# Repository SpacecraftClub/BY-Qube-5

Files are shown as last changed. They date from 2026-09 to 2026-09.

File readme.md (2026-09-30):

# BY-QUBE-5
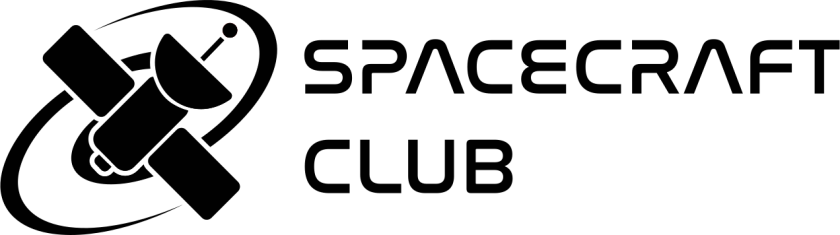
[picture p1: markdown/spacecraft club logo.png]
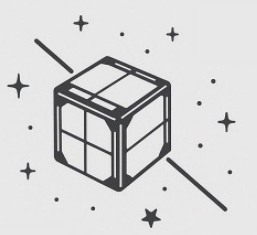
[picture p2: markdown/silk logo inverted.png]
<br>
The fith itteration of BYU Spacecraft's PocketQube project. Based on the success of BY-QUBE-4 we aim to itterate and improve on our previous designs.
## Preamble
For the last 4 years, undergraduate students have participated in the BY-QUBE 1p pocketqube program. 
### BY-QUBE-4
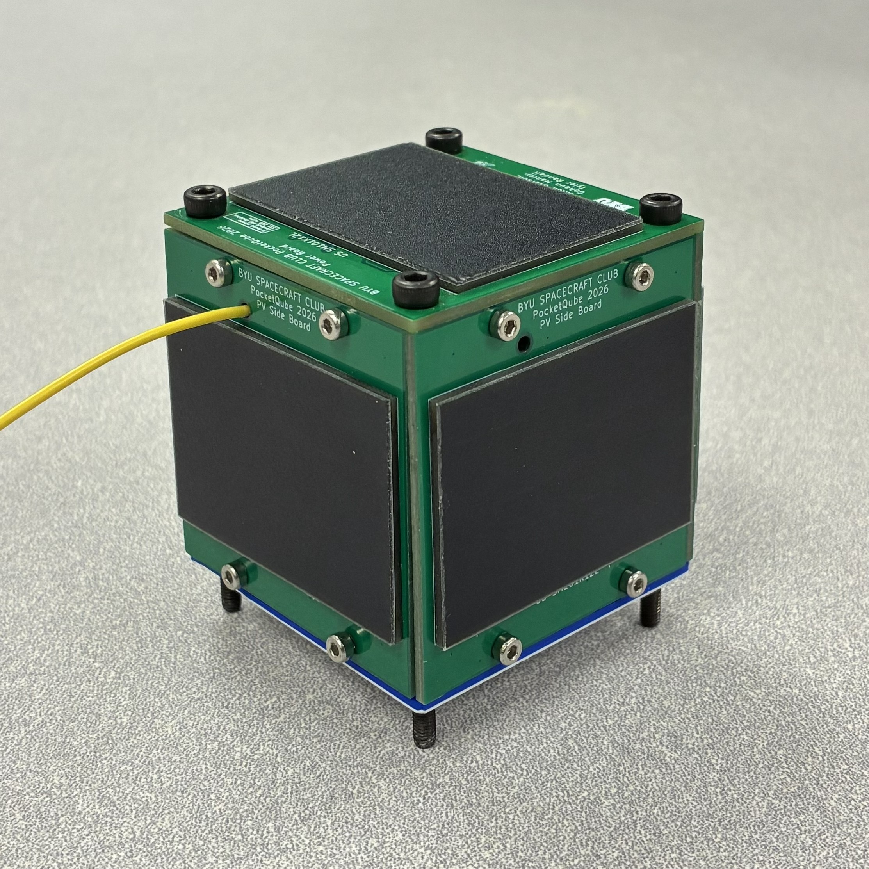
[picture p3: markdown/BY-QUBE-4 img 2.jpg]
BY-QUBE-4 1
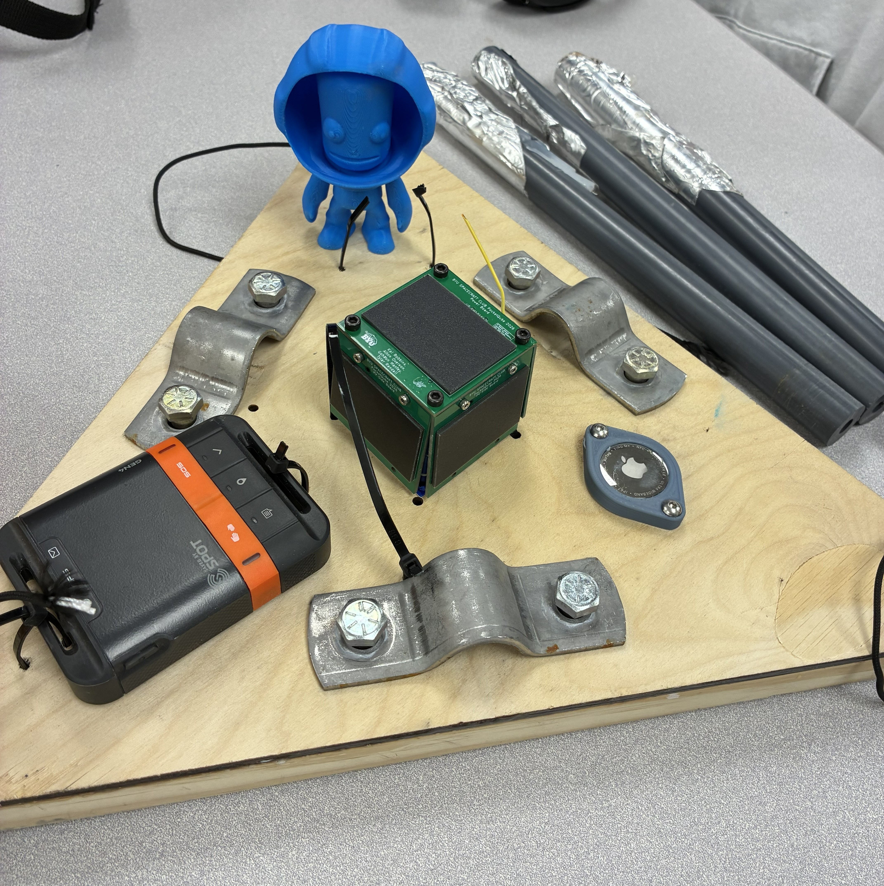
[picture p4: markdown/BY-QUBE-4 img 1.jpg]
BY-QUBE-4 1

## Improvements for this year
### Improved board stackup design
Using a blade design for interfacing the boards into eachother rather than crimped wire interfaces. This will increase durability, simplify the assembly process, and allow for easy swapping of subsystems as needed.

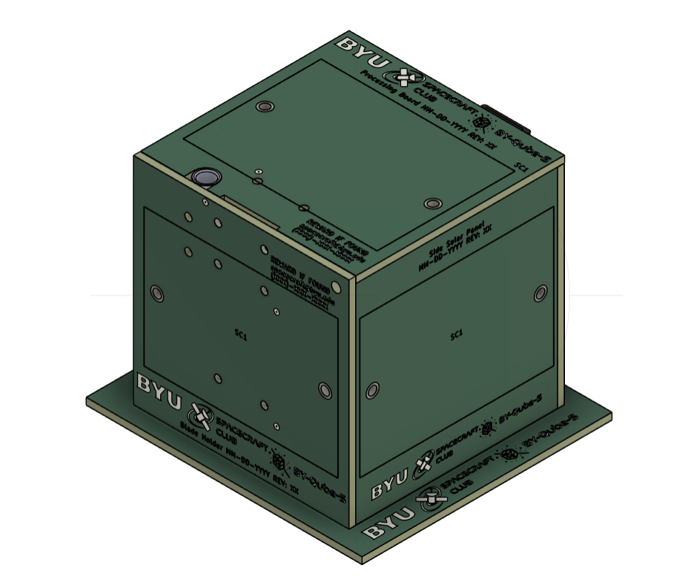
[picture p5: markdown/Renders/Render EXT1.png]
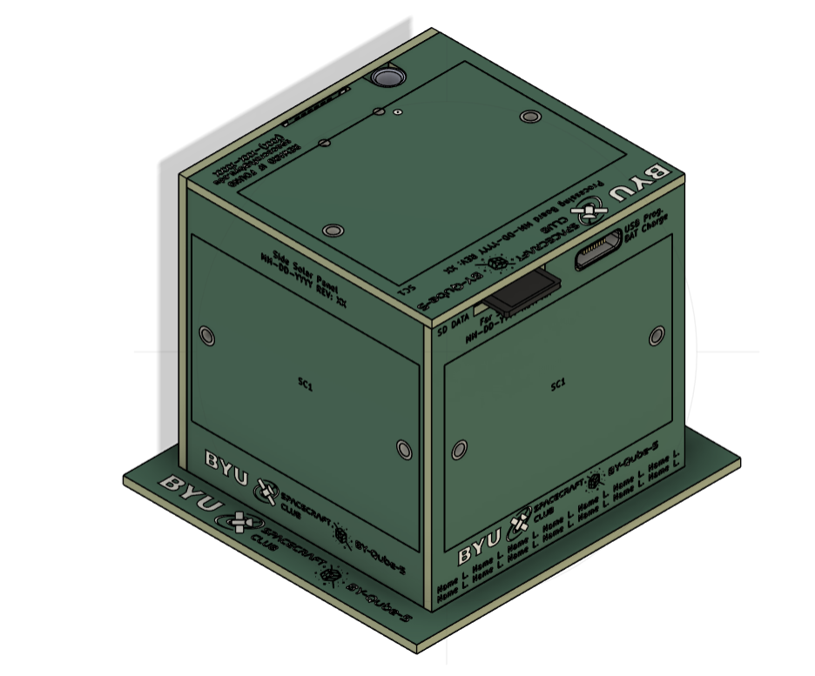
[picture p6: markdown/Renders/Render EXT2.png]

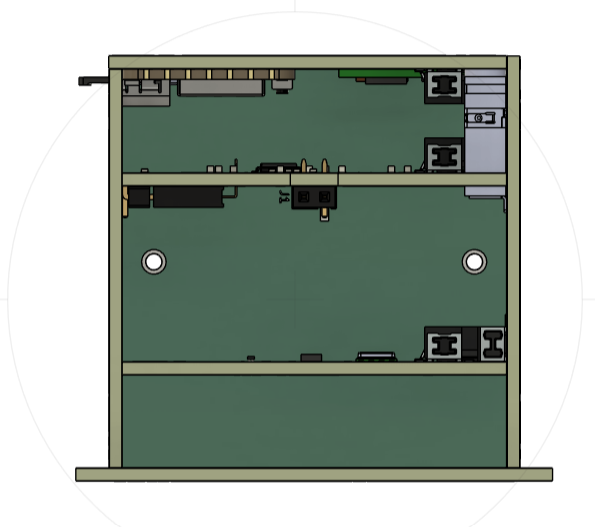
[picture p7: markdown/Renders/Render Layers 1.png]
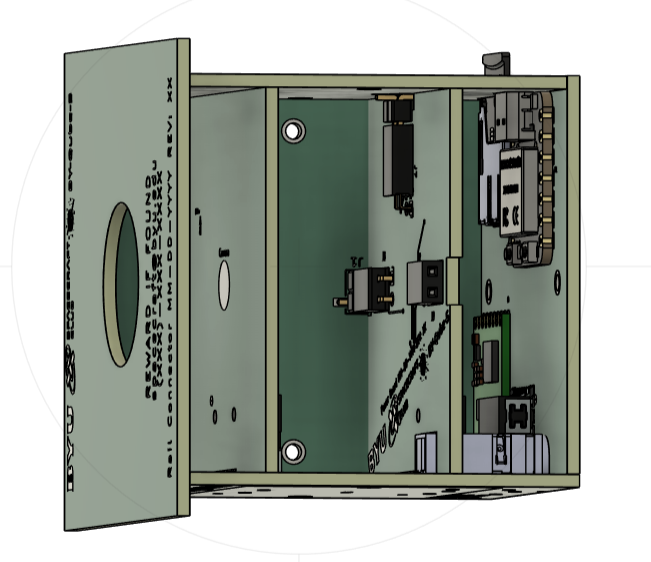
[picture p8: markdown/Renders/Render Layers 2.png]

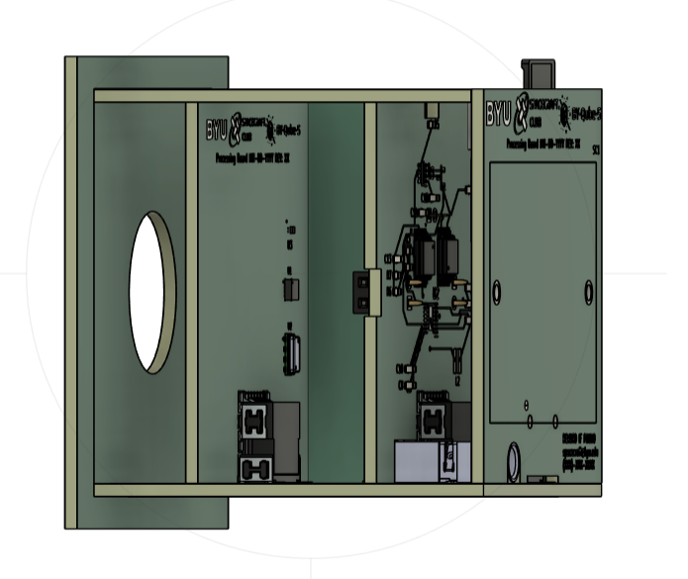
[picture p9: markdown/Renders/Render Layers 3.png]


##

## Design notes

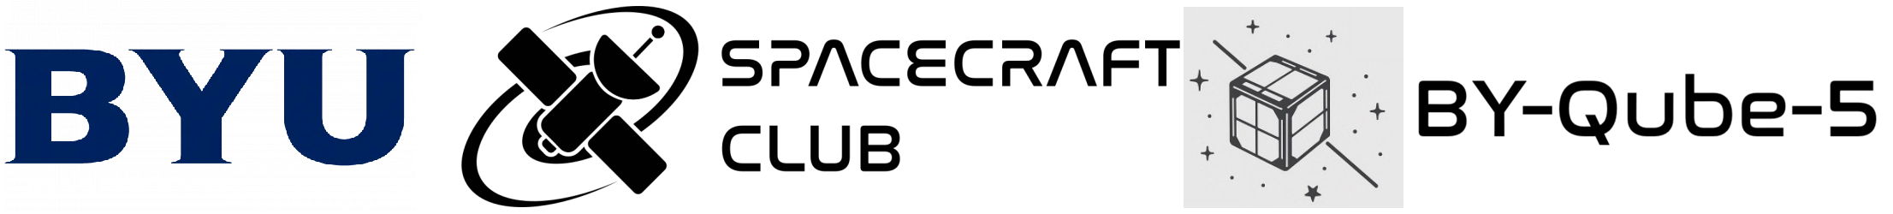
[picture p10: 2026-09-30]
Processing Board/Image Assets/Full Silk BY-Qube5.png

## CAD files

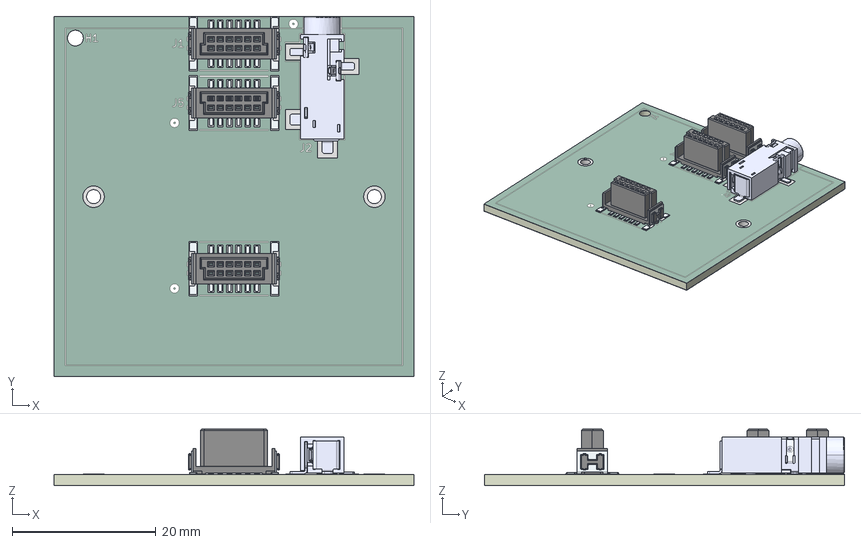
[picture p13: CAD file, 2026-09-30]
Blade Holder/Blade Holder Mockup.step
50.0 x 50.0 x 7.87 mm
Same_Sky_SJ-3524-SMT-TR
Blade Holder_pad
Blade Holder_silkscreen x 2
Blade Holder_soldermask x 2
Blade Holder_PCB

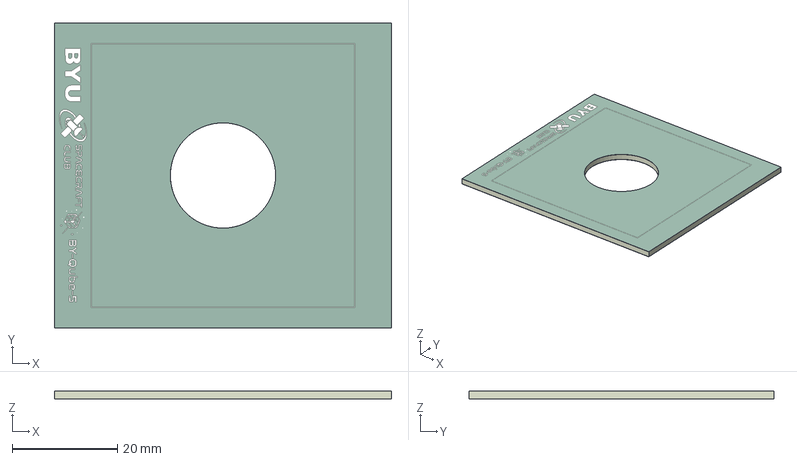
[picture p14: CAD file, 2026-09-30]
Bottom Rail Plate/Bottom Rail Mockup.step
64.0 x 58.0 x 1.66 mm
Bottom Rail Plate_silkscreen x 2
Bottom Rail Plate_soldermask x 2
Bottom Rail Plate_PCB

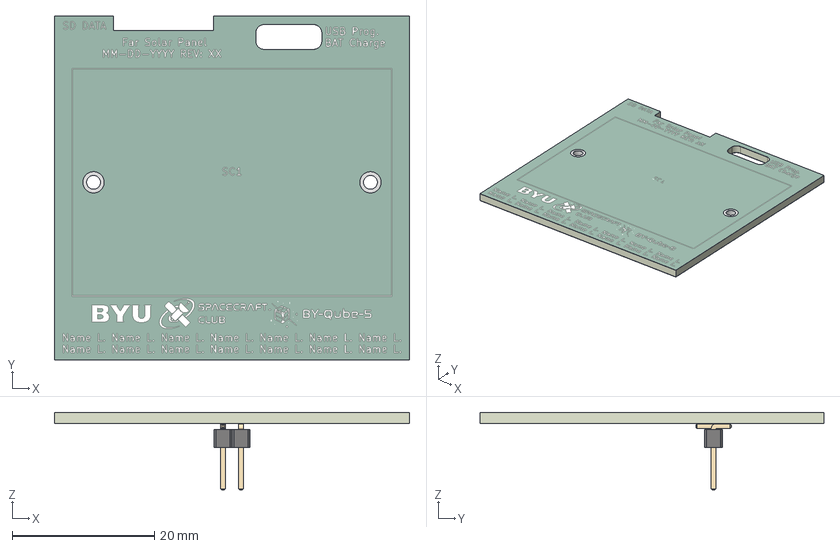
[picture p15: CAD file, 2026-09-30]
Far Solar Panel Board/Far Solar Mockup.step
50.0 x 48.4 x 11.0 mm
PinHeader_1x02_P2.54mm_Vertical_SMD_Pin1Right
Far Solar Panel Board_pad
Far Solar Panel Board_silkscreen x 2
Far Solar Panel Board_soldermask x 2
Far Solar Panel Board_PCB

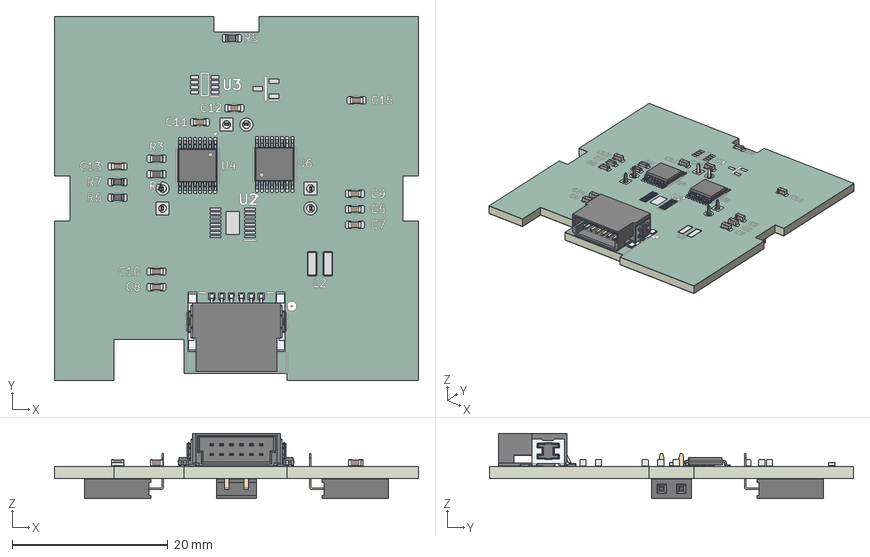
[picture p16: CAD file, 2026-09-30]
Power Board/Power Board Mockup.step
46.8 x 46.8 x 8.42 mm
C_0603_1608Metric x 9
R_0603_1608Metric x 5
TSSOP-16_4.4x5mm_P0.65mm x 2
PinSocket_1x02_P2.54mm_Horizontal x 3
Power Board_copper
Power Board_pad
Power Board_via
Power Board_silkscreen x 2
Power Board_soldermask x 2
Power Board_PCB

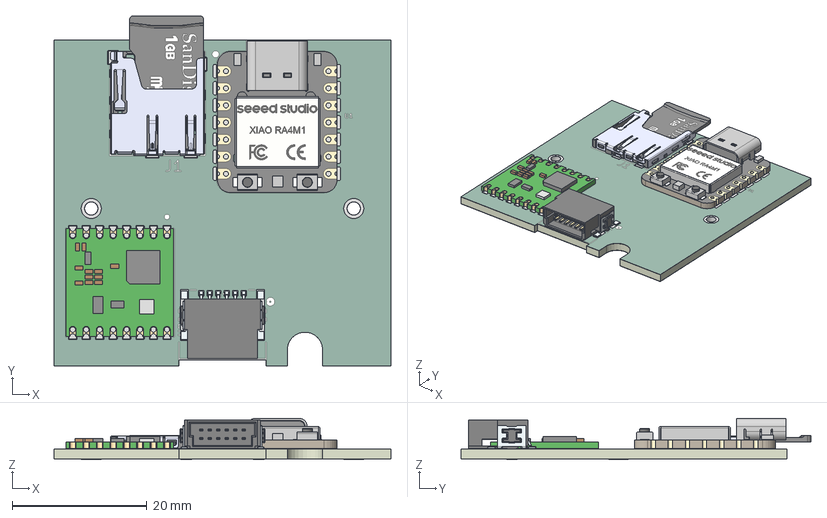
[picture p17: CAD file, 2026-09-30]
Processing Board/Processing Board Mockup.step
50.0 x 52.0 x 6.16 mm
BOSS-EXTRUDE14_8_
BOSS-EXTRUDE7_4_
BOSS-EXTRUDE7_3_
BOSS-EXTRUDE14_4_
BOSS-EXTRUDE14_2_
BOSS-EXTRUDE14_11_
BOSS-EXTRUDE7_7_
BOSS-EXTRUDE14_9_
BOSS-EXTRUDE14_3_
BOSS-EXTRUDE14_7_
MIRROR2
BOSS-EXTRUDE14_5_
BOSS-EXTRUDE14_12_
BOSS-EXTRUDE7_8_
BOSS-EXTRUDE7_1_
BOSS-EXTRUDE14_10_
BOSS-EXTRUDE7_9_
BOSS-EXTRUDE14_6_
BOSS-EXTRUDE14_1_
BOSS-EXTRUDE7_6_
BOSS-EXTRUDE7_2_
CUT-EXTRUDE5
BOSS-EXTRUDE7_5_
Button (1) x 2
Shield (1)
MEM2061-01-188-00-A_REVA
Micro_SD
RFM95W-868S2
Processing Board_pad
Processing Board_silkscreen x 2
Processing Board_soldermask x 2
Processing Board_PCB

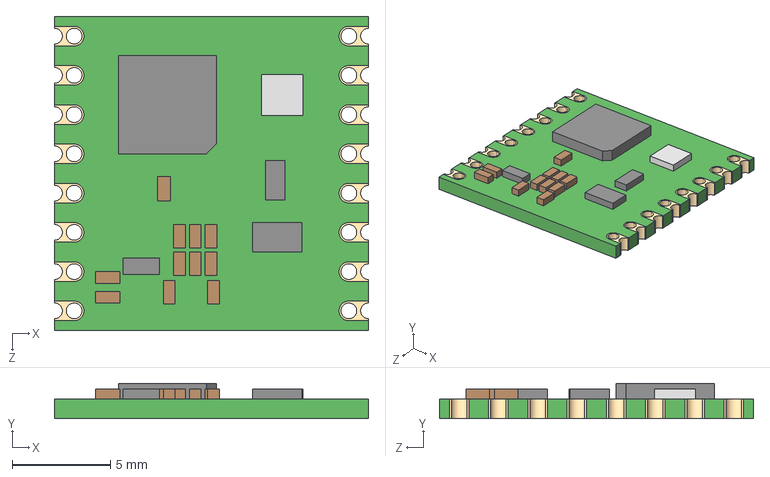
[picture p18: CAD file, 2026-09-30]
Processing Board/RFM95W-868S2/RFM95W-868S2.step
16.0 x 1.80 x 16.0 mm

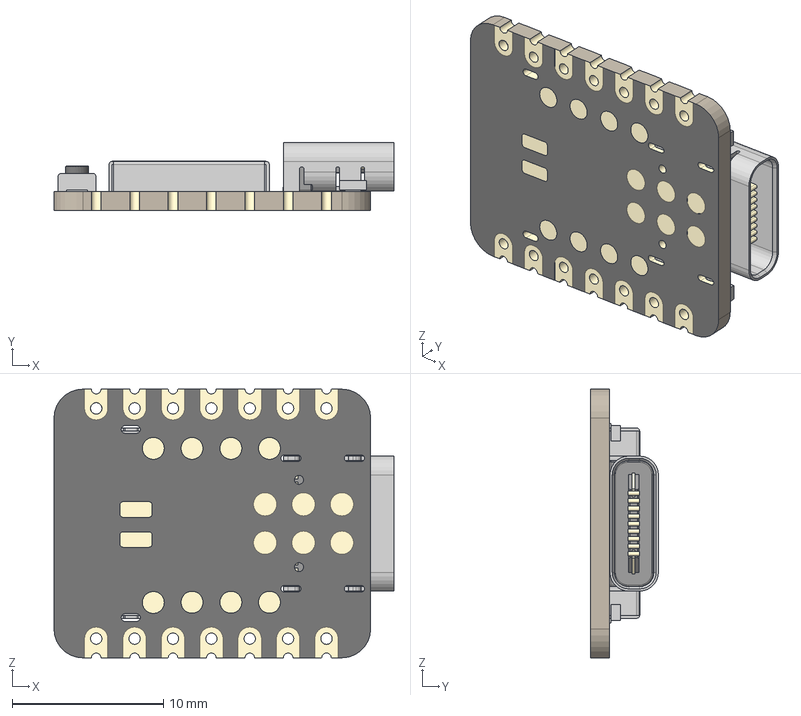
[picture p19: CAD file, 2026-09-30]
Processing Board/Seeed Studio XIAO Series Library/seeed-studio-xiao-ra4m1-v3.step
22.5 x 4.49 x 17.8 mm
BOSS-EXTRUDE14_8_
BOSS-EXTRUDE7_4_
BOSS-EXTRUDE7_3_
BOSS-EXTRUDE14_4_
BOSS-EXTRUDE14_2_
BOSS-EXTRUDE14_11_
BOSS-EXTRUDE7_7_
BOSS-EXTRUDE14_9_
BOSS-EXTRUDE14_3_
BOSS-EXTRUDE14_7_
MIRROR2
BOSS-EXTRUDE14_5_
BOSS-EXTRUDE14_12_
BOSS-EXTRUDE7_8_
BOSS-EXTRUDE7_1_
BOSS-EXTRUDE14_10_
BOSS-EXTRUDE7_9_
BOSS-EXTRUDE14_6_
BOSS-EXTRUDE14_1_
BOSS-EXTRUDE7_6_
BOSS-EXTRUDE7_2_
CUT-EXTRUDE5
BOSS-EXTRUDE7_5_
Button (1) x 2
Shield

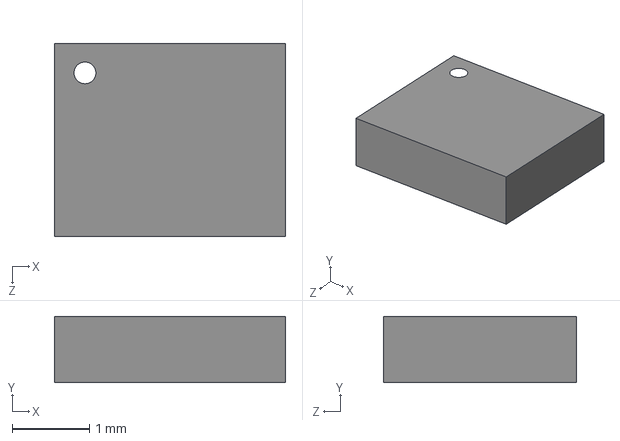
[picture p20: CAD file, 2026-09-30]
Sensor Board/LSMDSOXTR/LSM6DSOXTR.step
3.00 x 0.86 x 2.50 mm

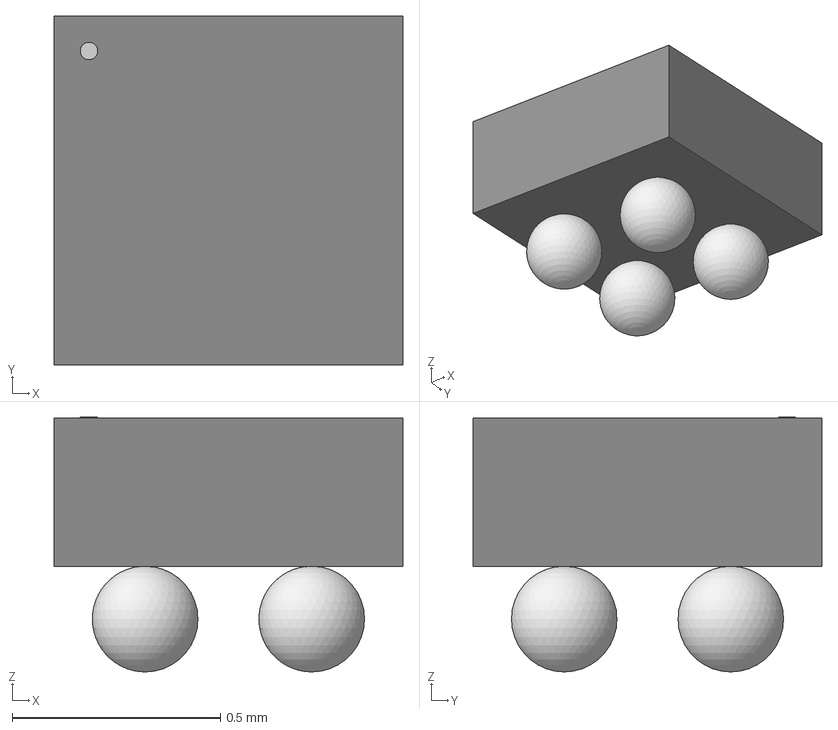
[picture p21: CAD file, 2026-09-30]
Sensor Board/MMC5603NJ/WLP4_0P82X0P82_MEM.step
0.838 x 0.838 x 0.612 mm

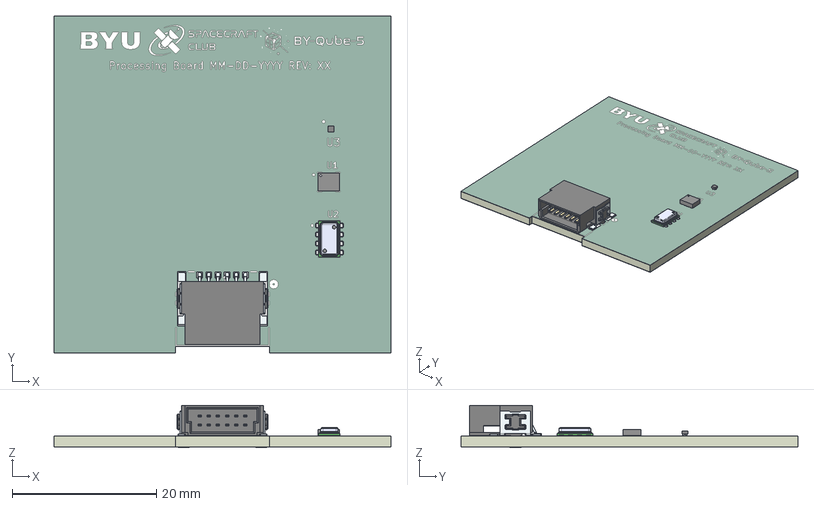
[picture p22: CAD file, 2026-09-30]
Sensor Board/Sensor Mockup.step
46.8 x 46.8 x 5.87 mm
MS5611-01BA03
WLP4_0P82X0P82_MEM
LSM6DSOXTR
Sensor Board_pad
Sensor Board_silkscreen x 2
Sensor Board_soldermask x 2
Sensor Board_PCB

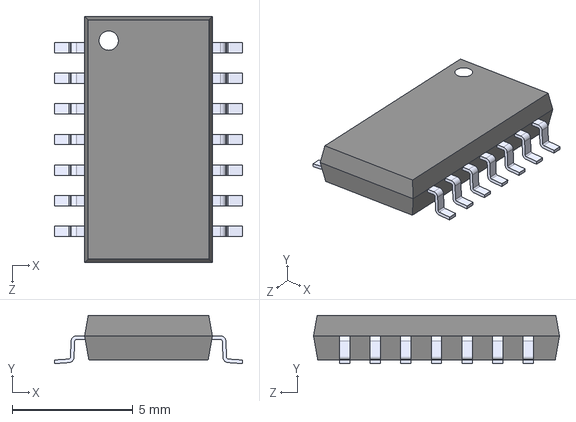
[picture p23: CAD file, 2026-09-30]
Sensor Board/SN74LVC125ANSR/SN74LVC125ANSR.step
7.80 x 2.00 x 10.2 mm

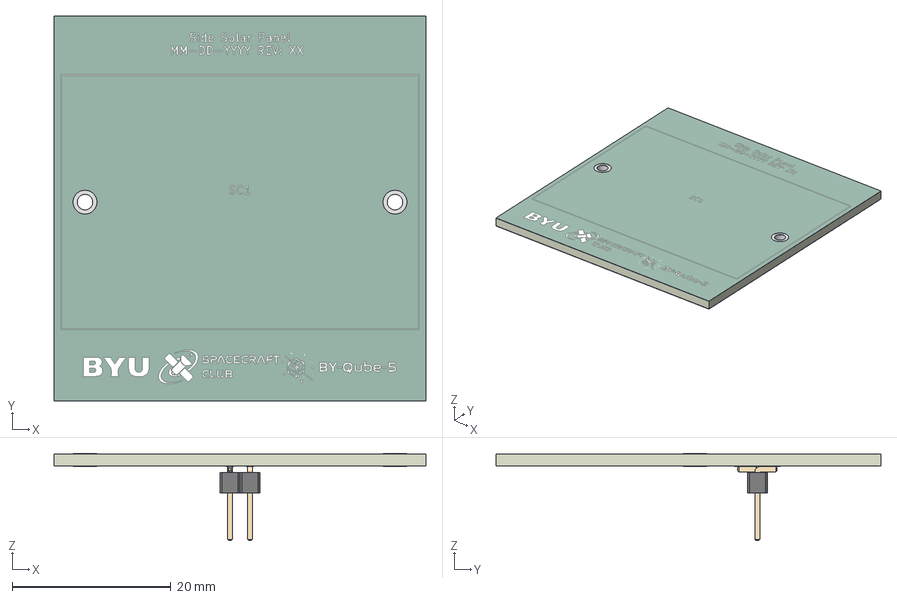
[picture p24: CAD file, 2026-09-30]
Side Solar Panel Board/Side Solar Mockup.step
46.8 x 48.4 x 11.0 mm
PinHeader_1x02_P2.54mm_Vertical_SMD_Pin1Right
Side Solar Panel Board_pad
Side Solar Panel Board_silkscreen x 2
Side Solar Panel Board_soldermask x 2
Side Solar Panel Board_PCB

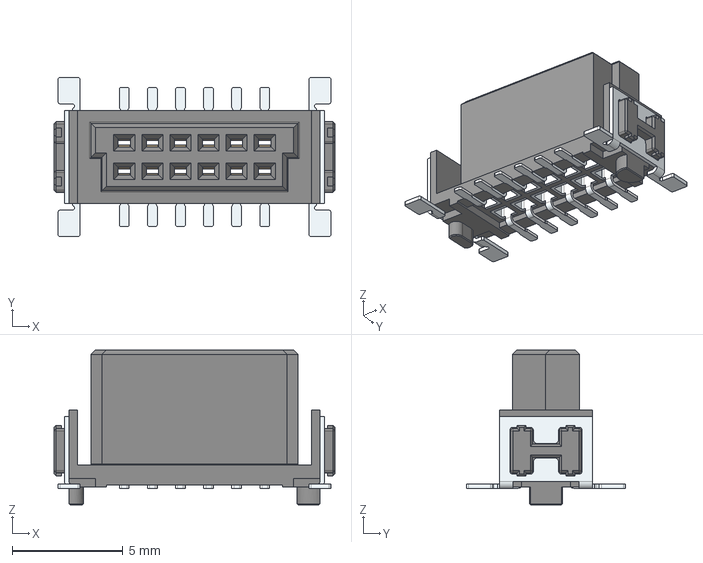
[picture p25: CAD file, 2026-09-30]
Blade Holder/M55-6001242R/m55-6001242r.stp
12.7 x 7.20 x 7.00 mm

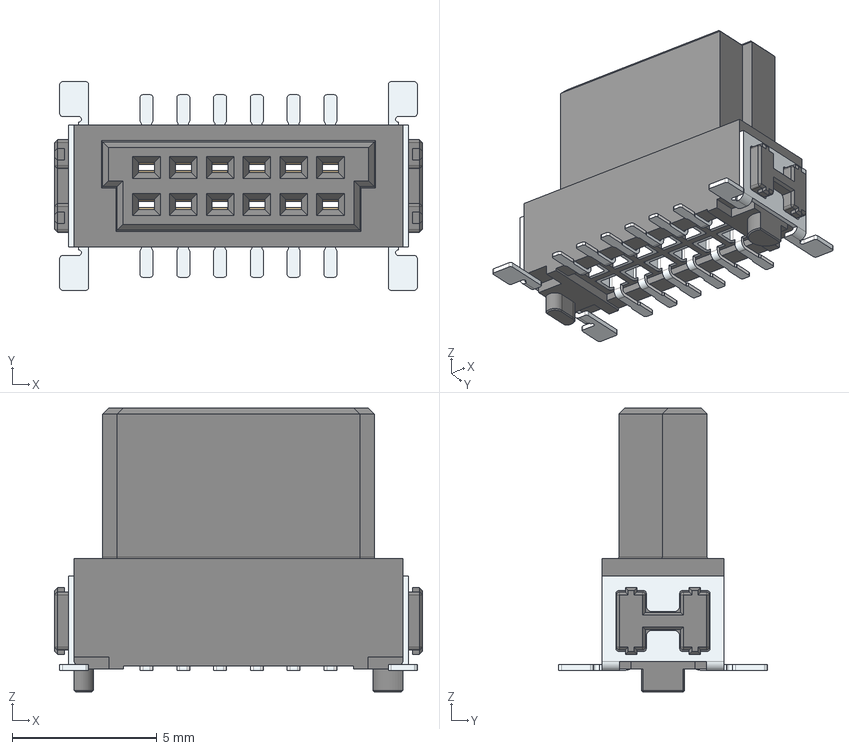
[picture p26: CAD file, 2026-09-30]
Processing Board/M55-6011242R/M55-6011242R.stp
12.7 x 7.20 x 9.80 mm
M55-60112_MOULD
M55-601_CONTACT x 12
M55-700_STRAP x 2

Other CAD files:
Processing Board/M55_7101242R/m55-7101242r.stp
Sensor Board/M55_7101242R/m55-7101242r.stp

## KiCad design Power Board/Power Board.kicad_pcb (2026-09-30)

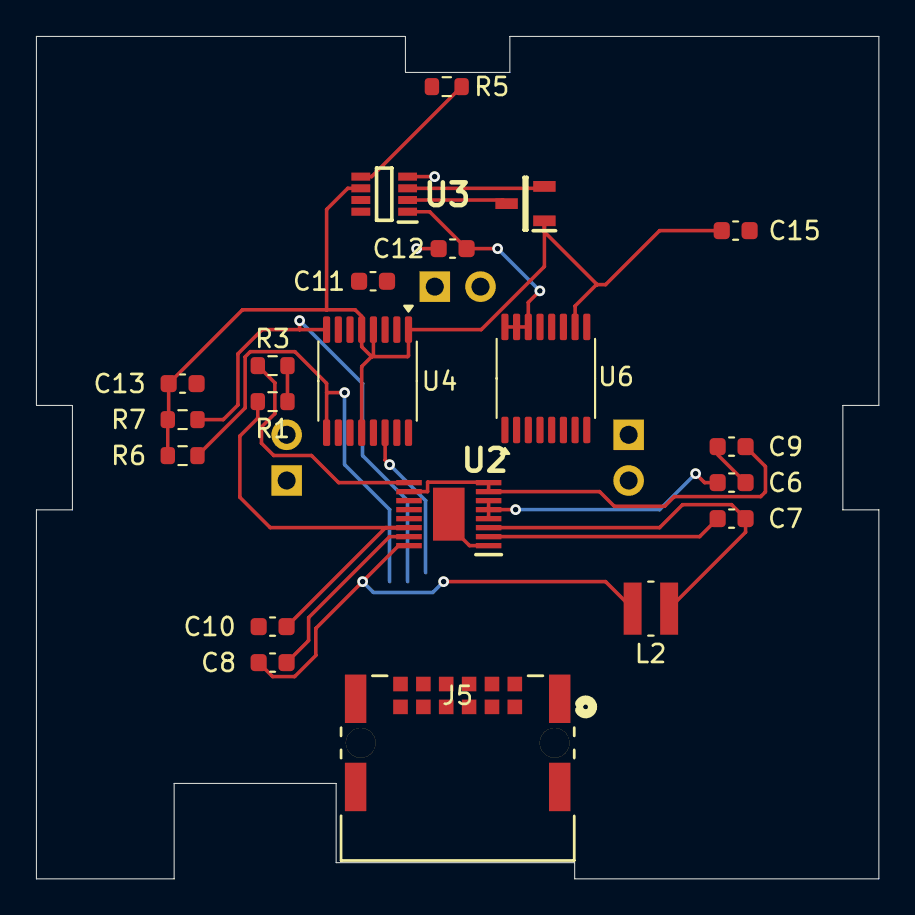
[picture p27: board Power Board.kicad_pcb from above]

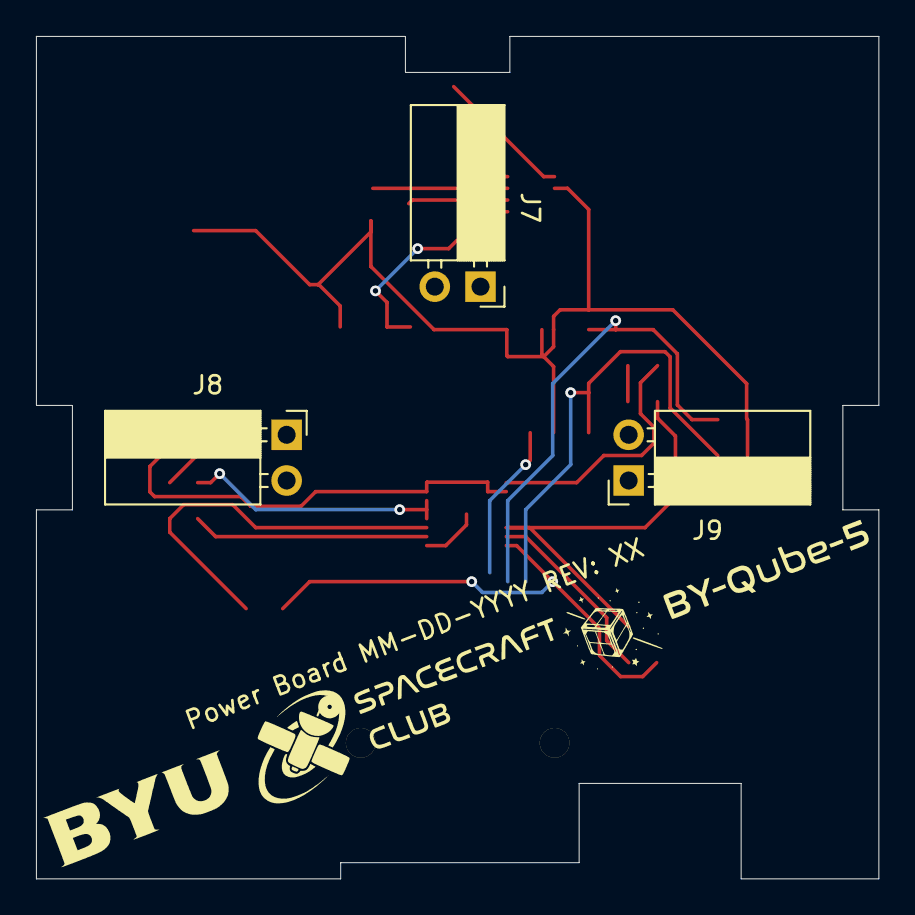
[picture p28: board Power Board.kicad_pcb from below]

Board: 2 copper layers, 46.8 x 46.8 mm, 25 parts (4 on the bottom side), 19 nets.

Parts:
C6, C13, C15: 1uF; C_0603_1608Metric
C7, C8: 22nF; C_0603_1608Metric
C9, C10: 4.7uF; C_0603_1608Metric
C11, C12: 1 uF; C_0603_1608Metric
G1: LOGO; silkLogo
J5: M55-7101242R; CONN_M55-7101242R_HRW
J7, J8, J9: Conn_01x02; PinSocket_1x02_P2.54mm_Horizontal
L2: 6.8uH; IND_EPL3015-682MLC
Q1: PNP; SOT96P237X111-3N
R1, R3: 200k; R_0603_1608Metric
R5: 1.3k; R_0603_1608Metric
R6, R7: 10K; R_0603_1608Metric
U2: LTC3130EMSE#PBF; LTC3130
U3: LTC4056ETS8-4.2#TRMPBF; LTC4056ETS8-4.2
U4, U6: INA260; TSSOP-16_4.4x5mm_P0.65mm

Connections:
/SCL: R6.2, U4.9 (SCL), U6.9 (SCL)
/SDA: R7.2, U4.8 (SDA), U6.8 (SDA)
/Vcharge+: C10.1, R1.1, U2.14 (VOUT), U6.1 (IN+), U6.2 (IN+), U6.3 (IN+), U6.12 (VBUS)
/Vcharge-: C12.1, U3.1 (VCC), U6.14 (IN-), U6.15 (IN-), U6.16 (IN-)
/Vout+: C13.1, C15.1, Q1.1 (C), R6.1, R7.1, U3.6 (BAT), U4.1 (IN+), U4.2 (IN+), U4.3 (IN+), U4.4 (A1), U4.5 (A0), U4.10 (VS), U4.12 (VBUS), U6.10 (VS)
/Vout-: U4.14 (IN-), U4.15 (IN-), U4.16 (IN-)
/Vsolar: C6.1, U2.4 (PVIN), U2.5 (VIN), U2.6 (RUN)
GND: C6.2, C9.2, C10.2, C11.2, C12.2, C13.2, C15.2, R5.2, U2.1 (GND_1), U2.11 (MODE), U2.12 (EXTVCC), U2.17 (GND_2), U3.4 (GND), U4.6 (GND), U4.11 (GND), U6.4 (A1), U6.5 (A0), U6.6 (GND), U6.11 (GND)
unnamed: Q1.2 (B), U3.3 (DRIVE)
unnamed: Q1.3 (E), U3.2 (ISENSE)
unnamed: R1.2, R3.1
unnamed: C7.1, U2.2 (BST1)
unnamed: C8.2, U2.15 (BST2)
unnamed: C9.1, U2.7 (VCC), U2.8 (MPPC), U2.10 (VS1/ILIM)
unnamed: C7.2, L2.1, U2.3 (SW1)
unnamed: C8.1, L2.2, U2.16 (SW2)
unnamed: R3.2, U2.9 (VS2/FB)
unnamed: R5.1, U3.5 (PROG)
unnamed: C11.1, U3.7 (TIMER/~SHDN)

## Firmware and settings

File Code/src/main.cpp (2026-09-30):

#include "compileOptions.h"

#if DEBUG
  #pragma message "Compiling in debug mode"
#endif

#define TEST_TIMING true
#define PRINT_SENSOR_CSV true

#include <Arduino.h>
#include <SdFat.h>
#include <SPI.h>
#include "pinDefinitions.h"
#include "powerMonitor.h"
#include "taskHandles.h"
#include "camera.h"
#include "sensor_logger.h"
#include "radio.h"

#define HAS_TASK_ELLAPSED(ms, lastExecution, period) ((((ms) - (lastExecution)) >= (period)) || ((lastExecution) > (ms)))

extern SENSOR_TASK* sensorTasks[NUM_SENSOR_TASKS];

extern CAMERA_TASK arducamMegaCameraContext;

SdFs SD_CARD;

uint64_t lastSensorRun = 0;
const uint32_t sensorPeriod_ms = 100;
uint64_t lastCSVSave = 0;

const uint32_t CSVSavePeriod = 1000;
uint64_t lastRadioTx = 0;
const uint32_t radioPeriod_ms = 5000;
uint64_t lastPhotoTaken;
const uint32_t photoShootPeriod = 15000;

void setup() {
  #if DEBUG
    Serial.begin(9600);
    delay(5000);
    Serial.println("\n\nStarting QubeSat");
  #endif
  SPI.begin();
  Wire.begin();
  pinMode(CAM_CS, OUTPUT);
  pinMode(RAD_CS, OUTPUT);
  pinMode(SD_CS, OUTPUT);
  digitalWrite(CAM_CS,HIGH);
  digitalWrite(RAD_CS, HIGH);
  digitalWrite(SD_CS,HIGH);

  //Initialize SD Card
  #if SD_ENABLE
  if(!SD_CARD.begin(SD_CONFIG)){
    Serial.println("SD Card Failed to initialize!");
  }
  #if FORMAT_SD_CARD
  if(SD_CARD.format(&Serial)){
    Serial.println("Reformatted the SD Card");
  } else {
    Serial.println("Failed to reformat the SD Card");
  }
  #endif
  #endif

  setupSensorTasks();
  runSensorTasks(true); // make sure they are up to speed
  lastCSVSave = millis() + CSVSavePeriod / 2;

  #if CAMERA_ENABLE
  TASK_RETURN_CODE returnCode =  arducamMegaCameraContext.setup(&arducamMegaCameraContext);

  if(returnCode != TASK_EXECUTION_OKAY){
    Serial.print("Failed to initialize Task ");
    Serial.print("[Camera]");
    Serial.print(", failed with error code: ");
    Serial.println(Task_Return_Code_Names[returnCode]);
  }
  #endif

  initializeLogger(sensorTasks, &arducamMegaCameraContext);

  #if RADIO_ENABLE
  TASK_RETURN_CODE radioReturnCode = initRadio(sensorTasks, NUM_SENSOR_TASKS);
  if(radioReturnCode != TASK_EXECUTION_OKAY){
    Serial.print("Failed to initialize Task ");
    Serial.print("[Radio]");
    Serial.print(", failed with error code: ");
    Serial.println(Task_Return_Code_Names[radioReturnCode]);
  } else {
    lastRadioTx = millis() + radioPeriod_ms / 2;
  }
  #endif

  #if DEBUG
  Serial.println("\nQubeSat Initialized\n\n");
  #endif
}

void loop() {
  #if TEST_TIMING
  static uint32_t sensors_WCET = 0;
  static uint32_t camera_WCET = 0;
  #endif

  uint64_t currMillis = millis();
  if(HAS_TASK_ELLAPSED(currMillis, lastCSVSave, CSVSavePeriod)){
    lastCSVSave = currMillis;
    lastSensorRun = currMillis;
    runSensorTasks(true);

    logNewData();

    #if (DEBUG & PRINT_SENSOR_CSV)
    static bool havePrintedLabels = false;
    if(!havePrintedLabels){
      havePrintedLabels = true;
      Serial.println();
      for(uint8_t sensor = 0; sensor < NUM_SENSOR_TASKS; sensor++){
        for(uint8_t data = 0; data < sensorTasks[sensor]->numDataTypes; data++){
          Serial.print(sensorTasks[sensor]->dataNames[data]);
          if(sensor != NUM_SENSOR_TASKS - 1 || data != sensorTasks[sensor]->numDataTypes - 1){
            Serial.print(',');
          }
        }
      }
      Serial.println();
    }
    for(uint8_t sensor = 0; sensor < NUM_SENSOR_TASKS; sensor++){
      for(uint8_t data = 0; data < sensorTasks[sensor]->numDataTypes; data++){
        Serial.print(sensorTasks[sensor]->dataCSV[data]);
        Serial.print(',');
      }
    }
    Serial.println();
    #endif

  } else if(HAS_TASK_ELLAPSED(currMillis, lastSensorRun, sensorPeriod_ms)){
    lastSensorRun = currMillis;
    runSensorTasks(false);
  }
  #if RADIO_ENABLE
  uint64_t radioMillis = millis();
  if(HAS_TASK_ELLAPSED(radioMillis, lastRadioTx, radioPeriod_ms)){
    lastRadioTx = radioMillis;
    TASK_RETURN_CODE radioReturnCode = transmitTelemetry();
    if(radioReturnCode != TASK_EXECUTION_OKAY){
      Serial.print("Failed to tick Task ");
      Serial.print("[Radio]");
      Serial.print(", failed with error code: ");
      Serial.println(Task_Return_Code_Names[radioReturnCode]);
    }
  }
  #endif
  #if TEST_TIMING
  uint32_t sensorExecutionTime = millis() - currMillis;
  if(sensorExecutionTime > sensors_WCET && millis() > currMillis){
    sensors_WCET = sensorExecutionTime;
    Serial.print("New Sensors WCET: ");
    Serial.println(sensors_WCET);
  }
  #endif
  #if CAMERA_ENABLE
  currMillis = millis(); // make sure to update before checking camera since sensor reading can take a while
  if(HAS_TASK_ELLAPSED(currMillis, lastPhotoTaken, photoShootPeriod)){
    lastPhotoTaken = currMillis;
    TASK_RETURN_CODE returnCode = arducamMegaCameraContext.tick(&arducamMegaCameraContext);
    if(returnCode != TASK_EXECUTION_OKAY){
      Serial.print("Failed to tick Task ");
      Serial.print("[Camera]");
      Serial.print(", failed with error code: ");
      Serial.println(Task_Return_Code_Names[returnCode]);
    }
  }
  #endif
  #if TEST_TIMING
  uint32_t cameraExecutionTime = millis() - currMillis;
  if(cameraExecutionTime > camera_WCET && millis() > currMillis){
    camera_WCET = cameraExecutionTime;
    Serial.print("New Camera WCET: ");
    Serial.println(camera_WCET);
  }
  #endif
  
}

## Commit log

2026-09-30 Initial KiCad Designs
    [Blade Holder Mockup.step, Blade Holder.kicad_pcb, Blade Holder.kicad_sch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]
2026-10-28 add pinout for processing boards
2026-11-03 add power and weight of components
2026-11-11 updated screwholes
    - added git ignore for .lck and .kicad_prl
2026-11-11 implement wires for connections to motherboard
2026-11-11 Sensor Schematic
